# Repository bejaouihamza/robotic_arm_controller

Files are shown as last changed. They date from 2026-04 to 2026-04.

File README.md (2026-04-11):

# 🦾 6-Axis Robotic Arm Controller — RP2040

> A high-performance embedded controller for 6-axis robotic arms featuring PIO-based jitter-free PWM, per-channel current sensing, real-time torque estimation, and hardware-level collision detection — no external sensors required.







---

## 📸 PCB Renders

| 3D Render | PCB Layout | Schematic |
|:---:|:---:|:---:|
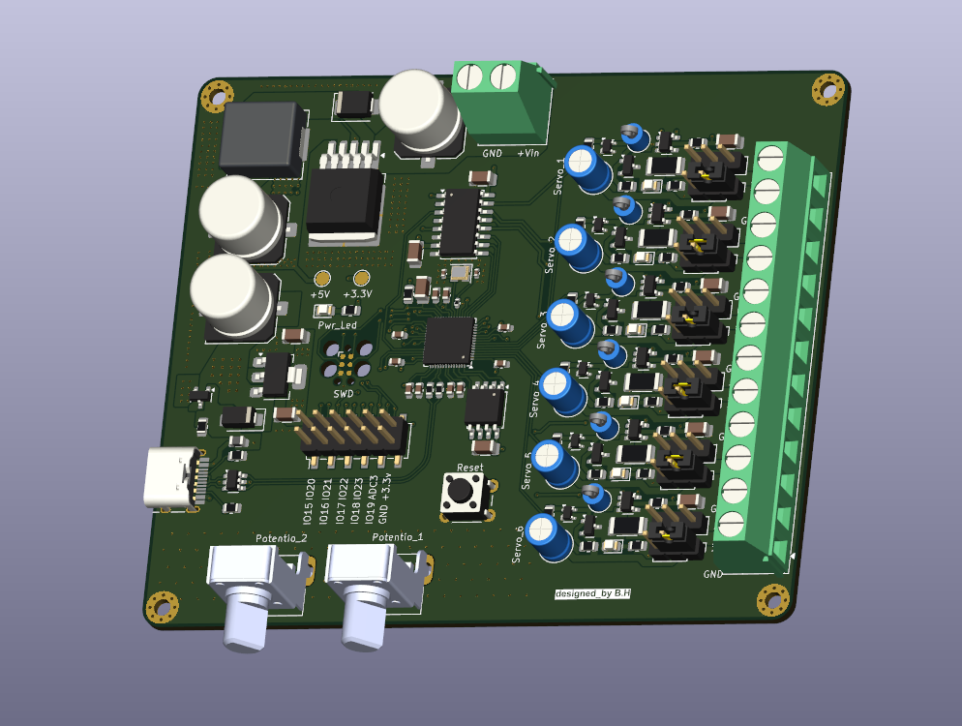
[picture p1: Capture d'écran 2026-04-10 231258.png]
3D Render
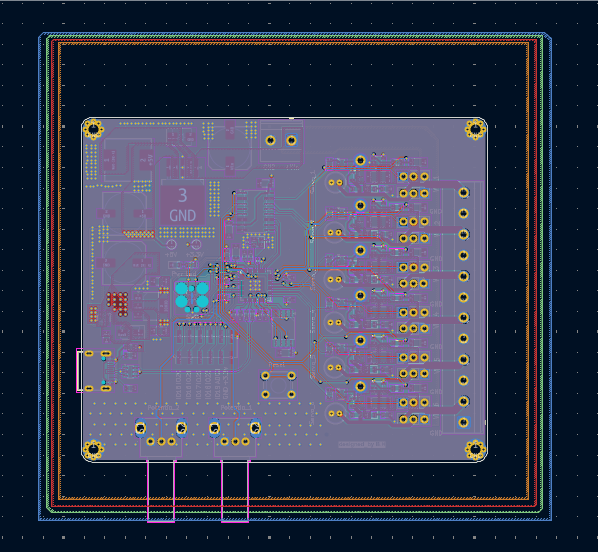
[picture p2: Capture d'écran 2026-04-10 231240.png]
PCB Layout
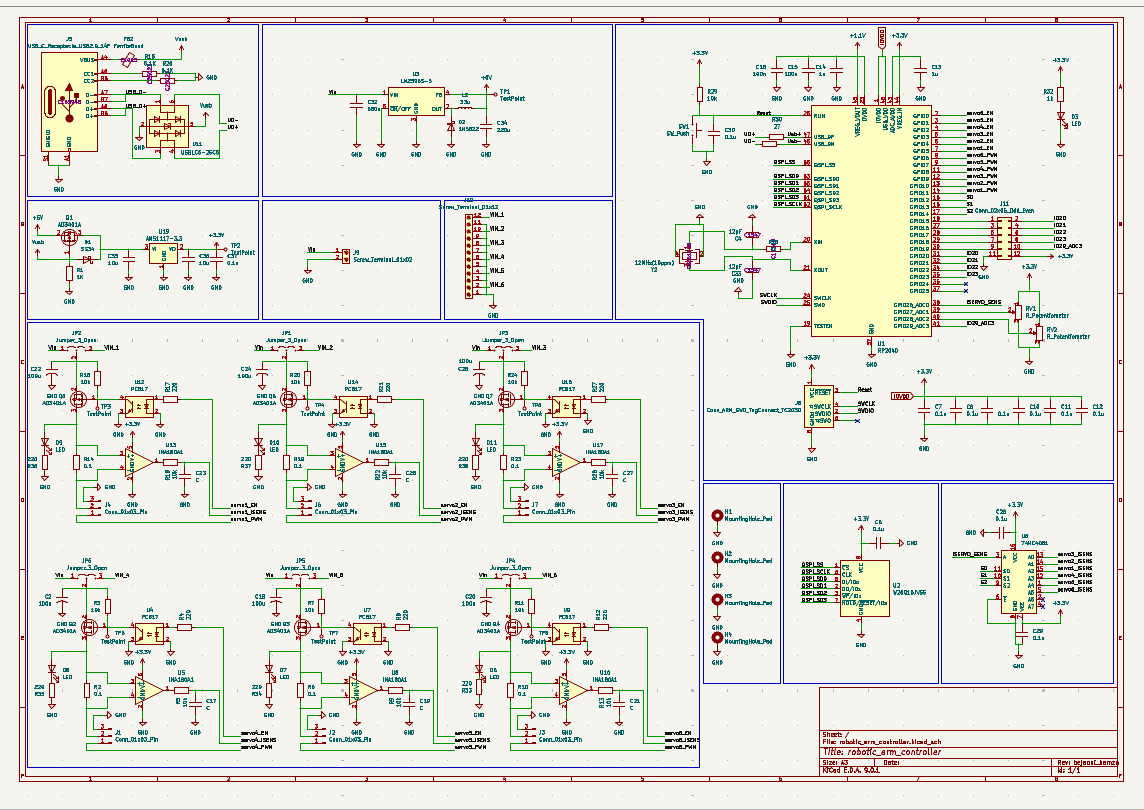
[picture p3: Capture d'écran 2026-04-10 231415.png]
Schematic
|  |  |  |

---

## ⚡ Key Specs

| Parameter | Value |
|---|---|
| MCU | Raspberry Pi RP2040 — Dual-core ARM Cortex-M0+ @ 133 MHz |
| Flash | 16MB W25Q16JV55 QSPI |
| Servo Channels | 6 independent, PIO-generated PWM |
| PWM Frequency | 50 Hz · 500–2500 µs pulse range |
| PWM Jitter | < 1 µs (PIO hardware, zero CPU involvement) |
| Current Sense | Per-channel INA180 amplifier (×20 gain, 10 mΩ shunt) |
| Peak Current | 10A total across all 6 channels |
| Input Voltage | 6V – 24V VIN + USB-C 5V |
| PCB | 4-Layer, KiCad |
| Firmware | MicroPython · C++ Pico SDK |
| License | CERN Open Hardware License v2 |

---

## 🧠 Core Concept

Traditional servo controllers simply send PWM signals. This board goes further:

```
MEASURE  →  ANALYZE  →  REACT
```

Every servo channel has a dedicated current sense amplifier. The RP2040 reads all six channels through a **74HC4051** analog multiplexer, continuously estimating torque, detecting collisions, and triggering per-channel shutdowns — all in real time.

---

## 🔩 Hardware & Components

### Processing Unit
- **RP2040** — Dual-core ARM Cortex-M0+ @ 133 MHz, 264KB SRAM, 8 PIO state machines
- **W25Q16JV55** — 16MB QSPI Flash for firmware and data logging
- **12 MHz Crystal** — Stable PLL reference for USB timing and precise PWM periods

### Power Management
- **Integrated 5V Buck Converter** — Logic supply and low-power servo rail
- **AMS1117-3.3** — Clean LDO for MCU and all analog circuitry
- **Auto power-path** — Seamless switching between USB-C (5V) and external VIN (6–24V)

### Servo Driver Block (×6 channels)
- **AO3401A P-MOSFET** — High-side switch per channel. Enables software-controlled power sequencing and instant per-joint emergency stops
- **INA180A1** — Current sense amplifier, gain ×20. Amplifies shunt voltage for ADC reading
- **10 mΩ Shunt Resistor** — In-series with each servo rail for current measurement

### Analog Signal Chain
- **74HC4051** — 8:1 CMOS analog multiplexer. Funnels all 6 current sense signals into a single ADC pin using only 3 GPIO select lines
- **JP1–JP6 Jumpers** — Per-channel voltage selection: position A = 5V buck, position B = direct VIN

### User Interface
- **RV1, RV2** — 10kΩ potentiometers mapped to Joint 1 & 2 for manual testing
- **D3** — User-programmable LED
- **Reset button** — Hardware reset
- **SWD header** — ARM Serial Wire Debug (J-Link / DAPLink / OpenOCD)

---

## 🔌 GPIO Pin Mapping

> GPIO 0–5 → Servo **Enable** (P-MOS high-side switches)  
> GPIO 6–11 → Servo **PWM** (PIO state machine outputs)

| GPIO | Net Name | Type | Connected To | Description |
|---|---|---|---|---|
| GPIO 0 | servo1_EN | GPIO OUT | AO3401A Gate Ch1 | High-side MOSFET enable — active HIGH |
| GPIO 1 | servo2_EN | GPIO OUT | AO3401A Gate Ch2 | High-side MOSFET enable — active HIGH |
| GPIO 2 | servo3_EN | GPIO OUT | AO3401A Gate Ch3 | High-side MOSFET enable — active HIGH |
| GPIO 3 | servo4_EN | GPIO OUT | AO3401A Gate Ch4 | High-side MOSFET enable — active HIGH |
| GPIO 4 | servo5_EN | GPIO OUT | AO3401A Gate Ch5 | High-side MOSFET enable — active HIGH |
| GPIO 5 | servo6_EN | GPIO OUT | AO3401A Gate Ch6 | High-side MOSFET enable — active HIGH |
| GPIO 6 | servo1_PWM | PIO OUT | Servo 1 signal wire | 50 Hz PIO PWM — sub-µs jitter |
| GPIO 7 | servo2_PWM | PIO OUT | Servo 2 signal wire | 50 Hz PIO PWM |
| GPIO 8 | servo3_PWM | PIO OUT | Servo 3 signal wire | 50 Hz PIO PWM |
| GPIO 9 | servo4_PWM | PIO OUT | Servo 4 signal wire | 50 Hz PIO PWM |
| GPIO 10 | servo5_PWM | PIO OUT | Servo 5 signal wire | 50 Hz PIO PWM |
| GPIO 11 | servo6_PWM | PIO OUT | Servo 6 signal wire | 50 Hz PIO PWM |
| GPIO 12 | S0 (MUX) | GPIO OUT | 74HC4051 Pin 11 | MUX address bit 0 |
| GPIO 13 | S1 (MUX) | GPIO OUT | 74HC4051 Pin 10 | MUX address bit 1 |
| GPIO 14 | S2 (MUX) | GPIO OUT | 74HC4051 Pin 9 | MUX address bit 2 |
| GPIO 18 | POT_1 | ADC0 IN | RV1 wiper | Manual Joint 1 input (0–3.3V = 0°–180°) |
| GPIO 19 | POT_2 | ADC1 IN | RV2 wiper | Manual Joint 2 input |
| GPIO 26 | MUX_A | GPIO OUT | 74HC4051 Pin 11 | MUX address line A |
| GPIO 27 | MUX_B | GPIO OUT | 74HC4051 Pin 10 | MUX address line B |
| GPIO 28 | MUX_C | GPIO OUT | 74HC4051 Pin 9 | MUX address line C |
| GPIO 29 | ISNS_ADC | ADC3 IN | 74HC4051 Common (Z) | Reads selected channel current sense voltage |
| USB-C | USB_DP/DM | USB 1.1 | USB-C connector | UF2 bootloader + CDC serial debug |
| SWD | SWCLK/SWDIO | DEBUG | SWD header (JB) | ARM Serial Wire Debug |

---

## 🏗️ PCB — 4-Layer Stackup

| Layer | Function | Details |
|---|---|---|
| **Layer 1 — Top** | Signal + Components | All SMD placement, fine-pitch routing (MCU, INA180, MUX) |
| **Layer 2 — GND** | Solid ground plane | Low-impedance return path, EMI shielding, heat spreading |
| **Layer 3 — Power** | Split power planes | 3.3V (MCU/sensors) · 5V (buck) · VIN (servo rails) |
| **Layer 4 — Bottom** | High-current traces | Servo power delivery, secondary signal routing |

A 4-layer design is essential here — with 6 servo channels switching simultaneously and up to 10A peak current, a 2-layer board would suffer from unacceptable EMI coupling and resistive heating.

---

## 📐 Physics — How It Works

### Motor Torque from Current

The fundamental relationship exploited by this board:

```
τ = Kₜ × I
```

A DC motor's torque is directly proportional to its armature current. `Kₜ` is the motor's torque constant (Nm/A). By measuring current through the INA180 shunt amplifiers, we measure torque — without any mechanical sensor.

### Current Sensing Chain

```
I (servo current)
  → V_shunt = I × R_shunt          (Ohm's Law across 10mΩ shunt)
  → V_out = V_shunt × 20           (INA180 ×20 amplification)
  → ADC = (V_out / 3.3V) × 65535  (RP2040 12-bit ADC)
  → I = (ADC / 65535 × 3.3) / (20 × 0.01)
```

At 2.5A (overload threshold): `V_shunt = 25mV → V_out = 500mV` — well within ADC range.

**Resolution:** ~0.25 mA per LSB → ~0.02 mNm torque resolution per LSB.

### Servo PWM Position Encoding

```
θ° = (t_pulse − 500µs) / 2000µs × 180°
```

| Pulse Width | Angle |
|---|---|
| 500 µs | 0° |
| 1500 µs | 90° (centre) |
| 2500 µs | 180° |

The RP2040's PIO state machines generate these pulses in hardware — completely independent of the CPU clock, eliminating software-induced jitter that corrupts positional accuracy.

### Why PIO Instead of Hardware PWM?

Hardware PWM slices share a clock divider. Reprogramming multiple channels simultaneously causes brief glitches. PIO state machines run from dedicated instruction memory, each executing its PWM loop independently — giving 6 perfectly phase-stable signals while freeing both CPU cores for inverse kinematics or vision tasks.

### Collision Detection — Torque Spike

When the arm hits an obstacle, the motor stalls. A stalled motor draws its locked-rotor current — far above normal running current:

```
Normal:  I ≈ 0.3–0.8 A  →  τ ≈ 0.025–0.068 Nm
Stall:   I → 2–4 A      →  τ → 0.17–0.34 Nm  ← triggers shutdown
```

The ADC scans all 6 channels continuously. A torque spike is detected within one scan cycle (~1 ms). The P-MOSFET cuts power within a single GPIO toggle (~10 ns).

---

## 🛡️ Safety System

| Feature | Description |
|---|---|
| **Torque Estimation** | τ = Kₜ × I, live on all 6 joints, ~0.02 mNm resolution |
| **Collision Detection** | Configurable torque threshold (default 0.20 Nm) triggers per-joint shutdown |
| **Overcurrent Protection** | Sustained current > 2.5A sets latching fault, cuts P-MOSFET |
| **Emergency Stop** | All 6 channels cut simultaneously via single function call |
| **Smooth Motion** | Interpolated moves with per-step collision check |
| **Power Sequencing** | Staggered joint enable (100ms delay) prevents inrush brownout |
| **Fault Latch** | Fault persists until software reset — prevents repeated thermal stress |

---

## 💻 Firmware

```python
# robotic_arm_controller.py
# GPIO 0-5  → Servo ENABLE (P-MOS high-side switches)
# GPIO 6-11 → Servo PWM    (PIO state machines)
import rp2, machine, time

SERVO_EN_PINS  = [0, 1, 2, 3, 4, 5]
SERVO_PWM_PINS = [6, 7, 8, 9, 10, 11]
MUX_SEL_PINS   = [12, 13, 14]
ADC_ISNS_PIN   = 29
POT1_PIN, POT2_PIN = 18, 19

SERVO_MIN_US = 500
SERVO_MAX_US = 2500
ISNS_GAIN    = 20
SHUNT_R      = 0.010
OVERLOAD_A   = 2.5
KT_NM_PER_A  = 0.085
COLLISION_NM = 0.20

@rp2.asm_pio(sideset_init=rp2.PIO.OUT_LOW)
def servo_pwm_pio():
    pull(block)          .side(0)
    mov(x, osr)
    label("high_loop")
    jmp(x_dec, "high_loop")  .side(1)
    pull(block)          .side(1)
    mov(x, osr)
    label("low_loop")
    jmp(x_dec, "low_loop")   .side(0)

class ServoChannel:
    def __init__(self, en_pin, pwm_pin, sm_id):
        self.en = machine.Pin(en_pin, machine.Pin.OUT, value=0)
        self.sm = rp2.StateMachine(sm_id, servo_pwm_pio,
                    freq=2_000_000, sideset_base=machine.Pin(pwm_pin))
        self.sm.active(1)
        self.angle = 90
        self.set_angle(90)

    def power_on(self):  self.en.value(1)
    def power_off(self): self.en.value(0)

    def set_angle(self, deg):
        deg = max(0.0, min(180.0, float(deg)))
        us  = SERVO_MIN_US + (deg / 180.0) * (SERVO_MAX_US - SERVO_MIN_US)
        self.sm.put(int(us * 2))
        self.sm.put(int((20000 - us) * 2))
        self.angle = deg

class CurrentSensor:
    def __init__(self):
        self.mux = [machine.Pin(p, machine.Pin.OUT) for p in MUX_SEL_PINS]
        self.adc = machine.ADC(ADC_ISNS_PIN)

    def read_channel(self, ch):
        for i, pin in enumerate(self.mux):
            pin.value((ch >> i) & 1)
        time.sleep_us(5)
        v = (self.adc.read_u16() / 65535) * 3.3
        return round(v / (ISNS_GAIN * SHUNT_R), 4)

    def read_all(self):
        return [self.read_channel(i) for i in range(6)]

class RoboticArm:
    def __init__(self):
        self.joints = [ServoChannel(SERVO_EN_PINS[i], SERVO_PWM_PINS[i], i) for i in range(6)]
        self.isns   = CurrentSensor()
        self.pot1   = machine.ADC(POT1_PIN)
        self.pot2   = machine.ADC(POT2_PIN)
        self.fault  = [False] * 6

    def power_up_sequence(self, delay_ms=100):
        for j in self.joints:
            j.power_on()
            time.sleep_ms(delay_ms)

    def emergency_stop(self):
        for j in self.joints: j.power_off()
        print("[E-STOP] All channels cut")

    def move_to(self, angles):
        for i, (j, deg) in enumerate(zip(self.joints, angles)):
            if not self.fault[i]: j.set_angle(deg)

    def torque_estimate(self):
        return [round(a * KT_NM_PER_A, 4) for a in self.isns.read_all()]

    def detect_collision(self, threshold_nm=COLLISION_NM):
        hits = []
        for i, t in enumerate(self.torque_estimate()):
            if t > threshold_nm and not self.fault[i]:
                self.joints[i].power_off()
                self.fault[i] = True
                hits.append(i)
                print(f"[COLLISION] Joint {i+1} @ {t:.4f} Nm")
        return hits

    def check_overload(self):
        for i, a in enumerate(self.isns.read_all()):
            if a > OVERLOAD_A and not self.fault[i]:
                self.joints[i].power_off()
                self.fault[i] = True
                print(f"[FAULT] Joint {i+1} overcurrent: {a:.3f} A")

    def smooth_move(self, targets, steps=50, delay_ms=10):
        start = [j.angle for j in self.joints]
        for s in range(1, steps + 1):
            t = s / steps
            self.move_to([start[i] + t * (targets[i] - start[i]) for i in range(6)])
            self.check_overload()
            if self.detect_collision(): return False
            time.sleep_ms(delay_ms)
        return True

    def read_manual(self):
        return (round((self.pot1.read_u16() / 65535) * 180, 1),
                round((self.pot2.read_u16() / 65535) * 180, 1))

    def status(self):
        c = self.isns.read_all()
        t = self.torque_estimate()
        print(f"{'Joint':<8}{'Angle':>8}{'Current':>10}{'Torque':>10}{'State':>8}")
        print("-" * 46)
        for i in range(6):
            print(f"J{i+1:<7}{self.joints[i].angle:>7.1f}°{c[i]:>9.3f}A{t[i]:>9.4f}Nm{'FAULT' if self.fault[i] else 'OK':>8}")

# ── Main ──────────────────────────────────────────────────
arm = RoboticArm()
arm.power_up_sequence(delay_ms=120)
arm.smooth_move([90, 90, 90, 90, 90, 90])

while True:
    j1, j2 = arm.read_manual()
    arm.move_to([j1, j2, 90, 90, 90, 90])
    arm.check_overload()
    arm.detect_collision()
    arm.status()
    time.sleep_ms(20)
```

---

## 🚀 Getting Started

**1. Power the board**
Connect VIN (6–24V) to the screw terminal. Set jumpers JP1–JP6:
- Position **A** → 5V internal buck (standard hobby servos)
- Position **B** → Direct VIN (high-torque servos above 7.4V)

**2. Flash firmware**
Hold `BOOT` on the back, press `RESET`. A drive named `RPI-RP2` appears. Drag your `.uf2` file onto it. Board reboots and runs automatically.

**3. Test with potentiometers**
RV1 and RV2 control Joint 1 and Joint 2 by default. Rotate to verify servo response before connecting the full arm.

**4. Monitor over serial**
Open any terminal at **115200 baud** on the USB-C port. `arm.status()` prints a live table of angle, current, torque, and fault state for all 6 joints.

**5. Tune collision thresholds**
Run the arm freely and log `status()` output. Set `COLLISION_NM` to ~1.5–2× the maximum torque observed during normal free movement.

**6. Extend with C++ for performance**
Run motion control on Core 0 and current sensing on Core 1 for fully parallel deterministic operation. Core 1 can achieve scan rates exceeding 10 kHz — enabling sub-millisecond collision response.

---

## ✅ Capabilities

- 6 independent PIO-generated PWM channels — sub-microsecond jitter
- Real-time torque estimation on every joint — no mechanical sensors
- Per-channel collision detection with configurable threshold
- Individual high-side MOSFET shutdown per channel
- Emergency stop — all 6 channels cut within a single GPIO toggle
- Smooth interpolated motion with mid-move collision check
- Staggered power-up to prevent inrush brownout
- Manual joint control via onboard potentiometers
- USB-C UF2 flashing — no external programmer required
- SWD debug header — J-Link / DAPLink / OpenOCD compatible
- Dual-core execution: motion on Core 0, sensing on Core 1
- MicroPython and C++ Pico SDK fully supported
- Per-servo independent voltage selection via JP1–JP6
- Live status table: angle, current, torque, fault per joint
- Latching fault system with software reset
- CERN Open Hardware License — free to modify and manufacture

---

## 📄 License

Released under the **CERN Open Hardware Licence Version 2 — Strongly Reciprocal (CERN-OHL-S v2)**.  
Free to study, modify, manufacture, and distribute — derivatives must remain open source.

---

<div align="center">Designed by <strong>B.H</strong></div>

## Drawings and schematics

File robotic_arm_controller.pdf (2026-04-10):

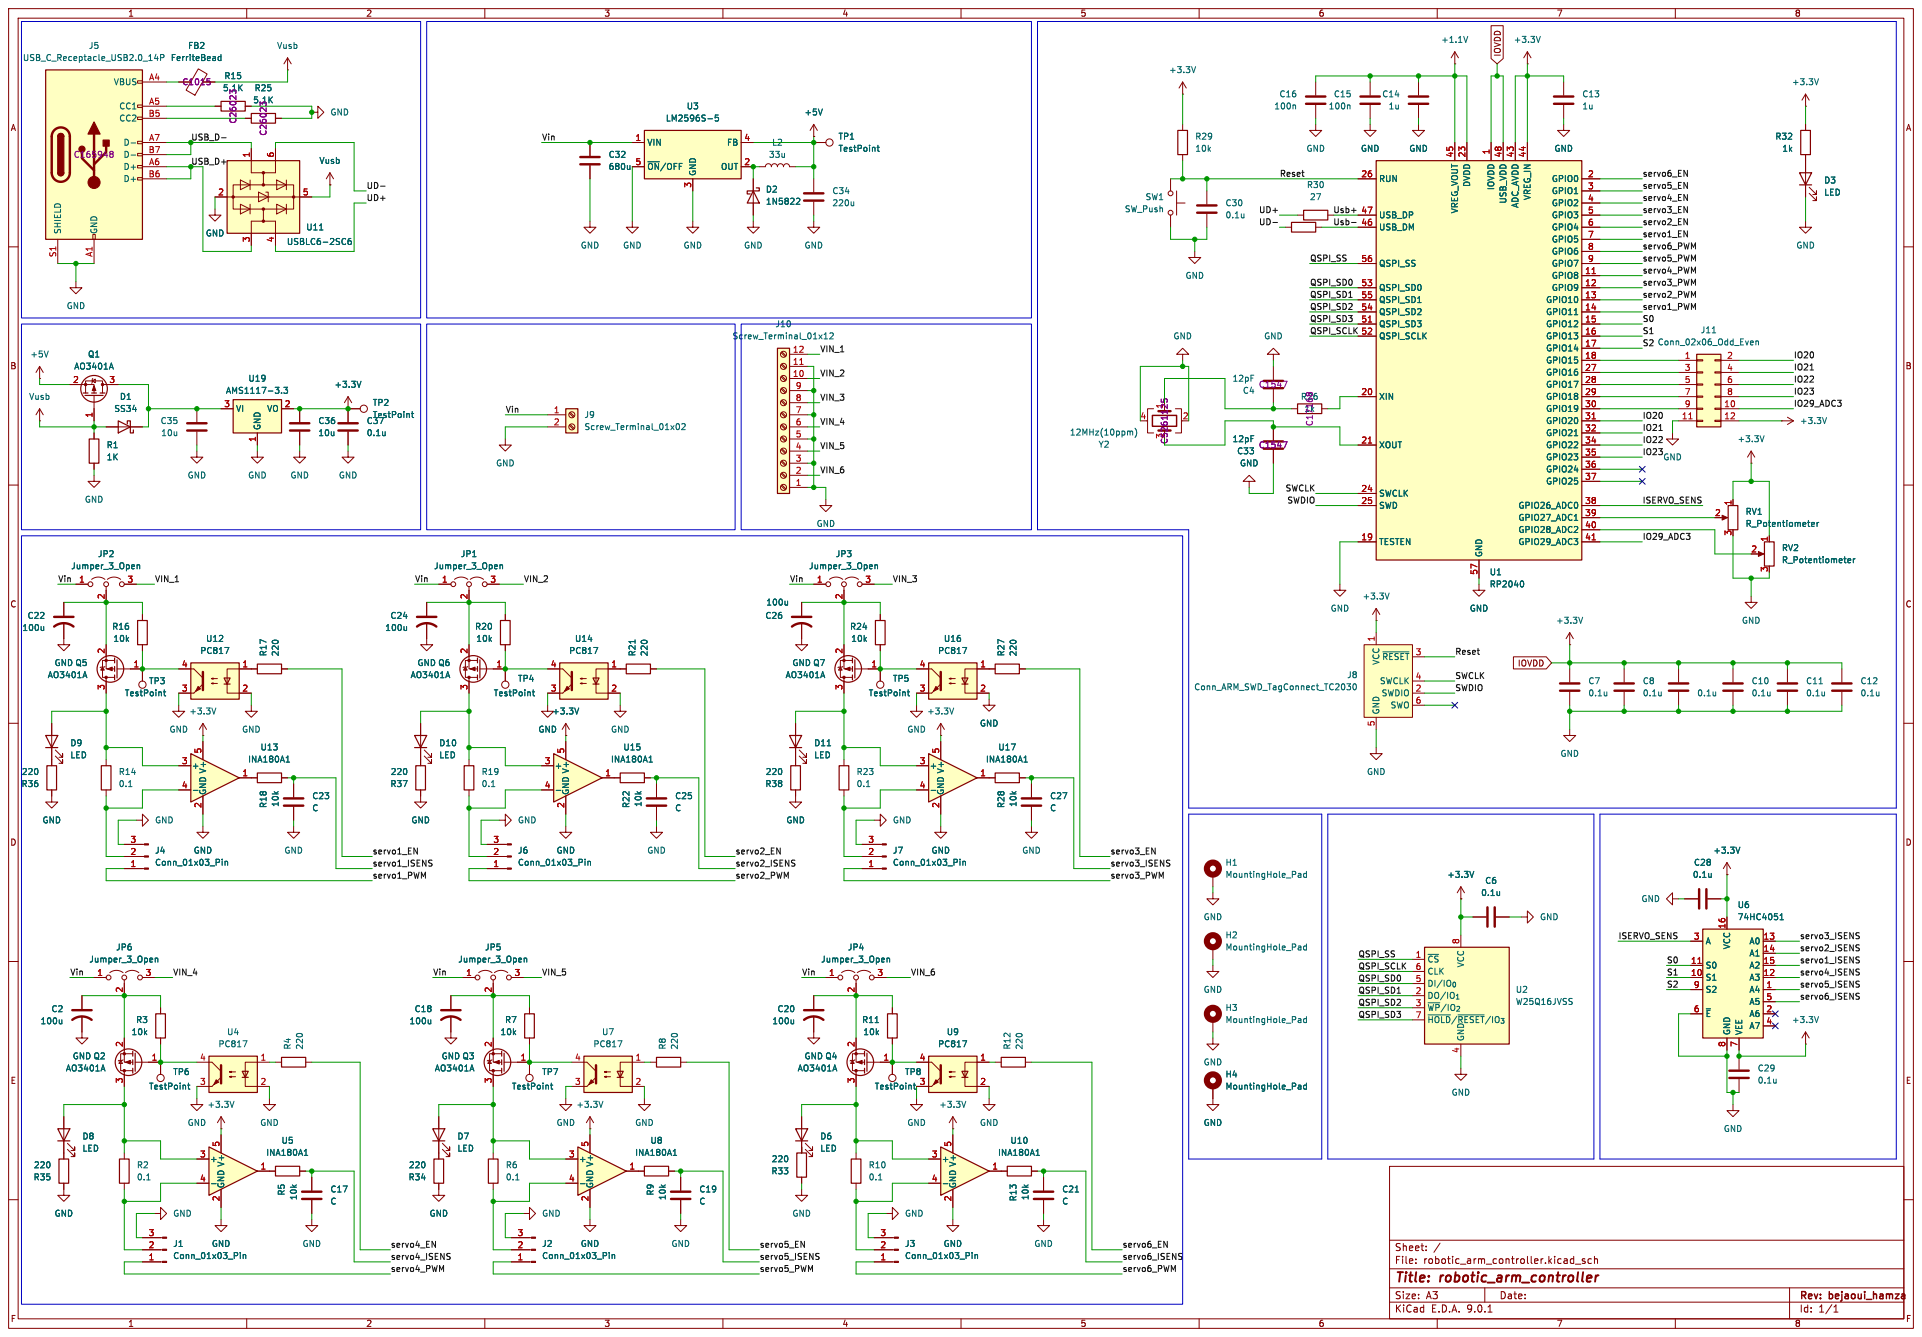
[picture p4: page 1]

5 ~{RESET}3 SWCLK 4 SWDIO 2 SWO 6

Id: 1/1 Title: robotic_arm_controller File: robotic_arm_controller.kicad_sch Sheet: / GND

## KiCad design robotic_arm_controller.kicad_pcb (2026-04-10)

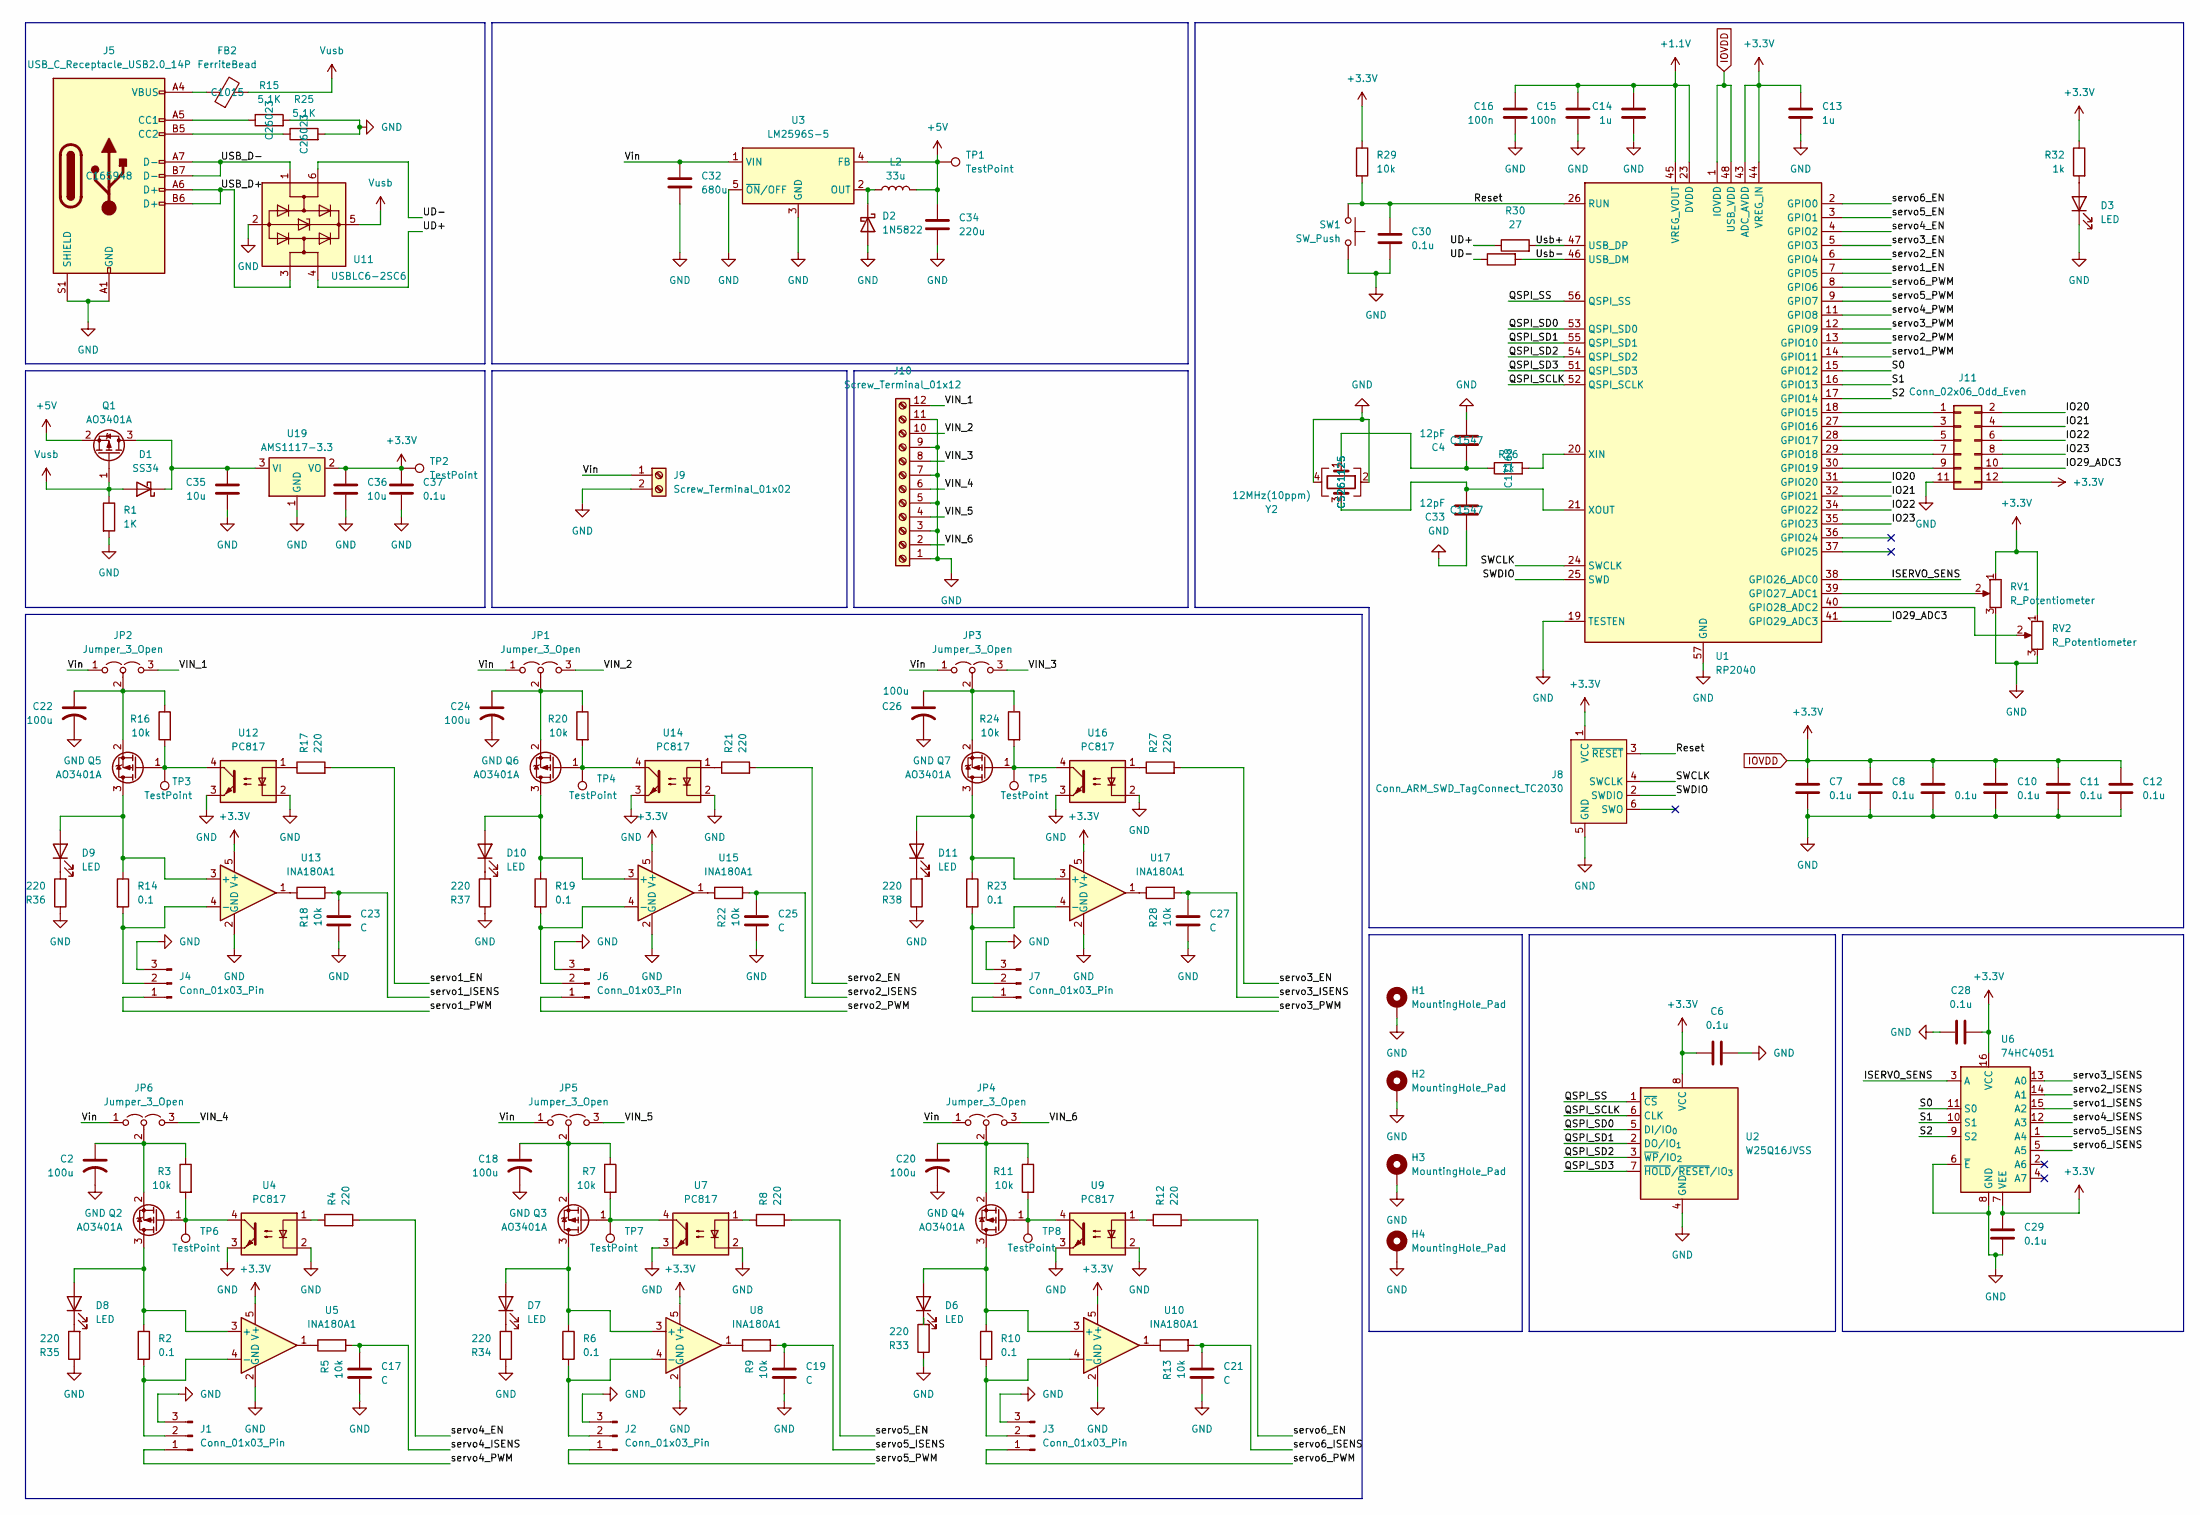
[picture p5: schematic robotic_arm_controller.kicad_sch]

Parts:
C2, C18, C20, C22, C24, C26: 100u; C_Radial_D5.0mm_H7.0mm_P2.00mm
C4, C33: 12pF; C_0402_1005Metric; MNF PART NUMBER C1547; LCSC Part # C1547
C6, C28, C29, C30, C37: 0.1u; C_1206_3216Metric
C7, C8, C9, C10, C11, C12: 0.1u; C_0603_1608Metric
C13, C14: 1u; C_0603_1608Metric
C15, C16: 100n; C_0603_1608Metric
C17, C19, C21, C23, C25, C27: C; C_1206_3216Metric
C32: 680u; C_Elec_10x10.2
C34: 220u; C_Elec_10x10.2
C35: 10u; C_Elec_10x10.2
C36: 10u; C_1206_3216Metric
D1: SS34; D_SMA
D2: 1N5822; D_SMB
D3, D6, D7, D8, D9, D10, D11: LED; LED_0805_2012Metric
FB2: FerriteBead; L_0805_2012Metric; LCSC Part # C1015
H1, H2, H3, H4: MountingHole_Pad; MountingHole_2.5mm_Pad_Via
J1, J2, J3, J4, J6, J7: Conn_01x03_Pin; PinHeader_1x03_P2.54mm_Vertical
J5: USB_C_Receptacle_USB2.0_14P; USB_C_Receptacle_HRO_TYPE-C-31-M-12; LCSC Part # C165948
J8: Conn_ARM_SWD_TagConnect_TC2030; Tag-Connect_TC2030-IDC-FP_2x03_P1.27mm_Vertical
J9: Screw_Terminal_01x02; TerminalBlock_Phoenix_MKDS-1,5-2-5.08_1x02_P5.08mm_Horizont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
J10: Screw_Terminal_01x12; TerminalBlock_Phoenix_MKDS-1,5-12-5.08_1x12_P5.08mm_Horizon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
J11: Conn_02x06_Odd_Even; PinHeader_2x06_P2.54mm_Vertical_SMD
JP1, JP2, JP3, JP4, JP5, JP6: Jumper_3_Open; PinHeader_1x03_P2.54mm_Vertical
L2: 33u; L_Bourns_SRP1050WA
Q1, Q2, Q3, Q4, Q5, Q6, Q7: AO3401A; SOT-23
R1: 1K; R_0805_2012Metric
R2, R6, R10, R14, R19, R23: 0.1; R_2010_5025Metric
R3, R5, R7, R9, R11, R13, R16, R18, R20, R22, R24, R28, R29: 10k; R_0805_2012Metric
R4, R8, R12, R17, R21, R27, R33, R34, R35, R36, R37, R38: 220; R_0805_2012Metric
R15, R25: 5.1K; R_0805_2012Metric; LCSC Part # C26023
R26: 1k; R_0402_1005Metric; MNF PART NUMBER C17168; LCSC Part # C17168
R30, R31: 27; R_0603_1608Metric
R32: 1k; R_0805_2012Metric
RV1, RV2: R_Potentiometer; TRIM_PT01-B115D-B103
SW1: SW_Push; SW_PUSH_6mm_H5mm
TP1, TP2: TestPoint; TestPoint_Pad_D2.0mm
TP3, TP4, TP5, TP6, TP7, TP8: TestPoint; TestPoint_Keystone_5005-5009_Compact
U1: RP2040; QFN-56-1EP_7x7mm_P0.4mm_EP3.2x3.2mm
U2: W25Q16JVSS; SOIC-8_5.3x5.3mm_P1.27mm
U3: LM2596S-5; TO-263-5_TabPin3
U4, U7, U9, U12, U14, U16: PC817; Analog_KS-4
U5, U8, U10, U13, U15, U17: INA180A1; SOT-23-5
U6: 74HC4051; SOIC-16W_5.3x10.2mm_P1.27mm
U11: USBLC6-2SC6; SOT-23-6; Manufacturer_Part_Number USBLC6-2SC6; Mouser Part Number 511-USBLC6-2SC6
U19: AMS1117-3.3; SOT-223-3_TabPin2
Y2: 12MHz(10ppm); Crystal_SMD_2520-4Pin_2.5x2.0mm; MNF PART NUMBER C5261125; LCSC Part # C5261125

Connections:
+1.1V: C14.2, C15.2, C16.2, U1.23 (DVDD), U1.45 (VREG_VOUT), U1.50 (DVDD)
+5V: C34.1, L2.2, Q1.2 (S), TP1.1, U3.4 (FB)
/IO20: J11.2, U1.31 (GPIO20)
/IO21: J11.4, U1.32 (GPIO21)
/IO22: J11.6, U1.34 (GPIO22)
/IO23: J11.8, U1.35 (GPIO23)
/IO29_ADC3: J11.10, U1.41 (GPIO29_ADC3)
/ISERVO_SENS: U1.38 (GPIO26_ADC0), U6.3 (A)
/QSPI_SCLK: U1.52 (QSPI_SCLK), U2.6 (CLK)
/QSPI_SD0: U1.53 (QSPI_SD0), U2.5 (DI/IO_{0})
/QSPI_SD1: U1.55 (QSPI_SD1), U2.2 (DO/IO_{1})
/QSPI_SD2: U1.54 (QSPI_SD2), U2.3 (~WP/IO_{2})
/QSPI_SD3: U1.51 (QSPI_SD3), U2.7 (~HOLD/~RESET/IO_{3})
/QSPI_SS: U1.56 (QSPI_SS), U2.1 (~CS)
/Reset: C30.2, J8.3 (~RESET), R29.2, SW1.2, U1.26 (RUN)
/S0: U1.15 (GPIO12), U6.11 (S0)
/S1: U1.16 (GPIO13), U6.10 (S1)
/S2: U1.17 (GPIO14), U6.9 (S2)
/SWCLK: J8.4 (SWCLK), U1.24 (SWCLK)
/SWDIO: J8.2 (SWDIO), U1.25 (SWD)
/UD+: R30.1, U11.4 (I/O2)
/UD-: R31.1, U11.6 (I/O1)
/USB_D+: J5.A6 (D+), J5.B6 (D+), U11.3 (I/O2)
/USB_D-: J5.A7 (D-), J5.B7 (D-), U11.1 (I/O1)
/Usb+: R30.2, U1.47 (USB_DP)
/Usb-: R31.2, U1.46 (USB_DM)
/VIN_1: J10.12, JP2.3 (B)
/VIN_2: J10.10, JP1.3 (B)
/VIN_3: J10.8, JP3.3 (B)
/VIN_4: J10.6, JP6.3 (B)
/VIN_5: J10.4, JP5.3 (B)
/VIN_6: J10.2, JP4.3 (B)
/Vin: C32.1, J9.1, JP1.1 (A), JP2.1 (A), JP3.1 (A), JP4.1 (A), JP5.1 (A), JP6.1 (A), U3.1 (VIN)
/servo1_EN: R17.2, U1.7 (GPIO5)
/servo1_ISENS: C23.1, R18.2, U6.15 (A2)
/servo1_PWM: J4.1, U1.14 (GPIO11)
/servo2_EN: R21.2, U1.6 (GPIO4)
/servo2_ISENS: C25.1, R22.2, U6.14 (A1)
/servo2_PWM: J6.1, U1.13 (GPIO10)
/servo3_EN: R27.2, U1.5 (GPIO3)
/servo3_ISENS: C27.1, R28.2, U6.13 (A0)
/servo3_PWM: J7.1, U1.12 (GPIO9)
/servo4_EN: R4.2, U1.4 (GPIO2)
/servo4_ISENS: C17.1, R5.2, U6.12 (A3)
/servo4_PWM: J1.1, U1.11 (GPIO8)
/servo5_EN: R8.2, U1.3 (GPIO1)
/servo5_ISENS: C19.1, R9.2, U6.1 (A4)
/servo5_PWM: J2.1, U1.9 (GPIO7)
/servo6_EN: R12.2, U1.2 (GPIO0)
/servo6_ISENS: C21.1, R13.2, U6.5 (A5)
/servo6_PWM: J3.1, U1.8 (GPIO6)
GND: C2.2, C4.2, C6.2, C7.1, C8.1, C9.1, C10.1, C11.1, C12.1, C13.1, C14.1, C15.1, C16.1, C17.2, C18.2, C19.2, C20.2, C21.2, C22.2, C23.2, C24.2, C25.2, C26.2, C27.2, C28.1, C29.1, C30.1, C32.2, C33.1, C34.2, C35.2, C36.2, C37.2, D2.2 (A), D3.1 (K), H1.1, H2.1, H3.1, H4.1, J1.3, J2.3, J3.3, J4.3, J5.A1 (GND), J5.A12 (GND), J5.B1 (GND), J5.B12 (GND), J5.S1 (SHIELD), J6.3, J7.3, J8.5 (GND), J9.2, J10.1, J10.3, J10.5, J10.7, J10.9, J10.11, J11.11, R1.2, R15.2, R25.2, R33.1, R34.1, R35.1, R36.1, R37.1, R38.1, RV1.3, RV2.3, SW1.1, U1.19 (TESTEN), U1.57 (GND), U2.4 (GND), U3.3 (GND), U3.5 (~ON/OFF), U4.2, U4.3, U5.2 (GND), U6.6 (~E), U6.8 (GND), U7.2, U7.3, U8.2 (GND), U9.2, U9.3, U10.2 (GND), U11.2 (GND), U12.2, U12.3, U13.2 (GND), U14.2, U14.3, U15.2 (GND), U16.2, U16.3, U17.2 (GND), U19.1 (GND), Y2.2, Y2.4
IOVDD: C6.1, C7.2, C8.2, C9.2, C10.2, C11.2, C12.2, C13.2, C28.2, C29.2, C36.1, C37.1, J8.1 (VCC), J11.12, R29.1, R32.1, RV1.1, RV2.1, TP2.1, U1.1 (IOVDD), U1.10 (IOVDD), U1.22 (IOVDD), U1.33 (IOVDD), U1.42 (IOVDD), U1.43 (ADC_AVDD), U1.44 (VREG_IN), U1.48 (USB_VDD), U1.49 (IOVDD), U2.8 (VCC), U5.5 (V+), U6.7 (VEE), U6.16 (VCC), U8.5 (V+), U10.5 (V+), U13.5 (V+), U15.5 (V+), U17.5 (V+), U19.2 (VO)
unnamed: C4.1, R26.1, Y2.1
unnamed: C35.1, D1.1 (K), Q1.3 (D), U19.3 (VI)
unnamed: D2.1 (K), L2.1, U3.2 (OUT)
unnamed: D3.2 (A), R32.2
unnamed: D6.2 (A), Q4.3 (D), R10.1, U10.3 (+)
unnamed: D6.1 (K), R33.2
unnamed: D7.2 (A), Q3.3 (D), R6.1, U8.3 (+)
unnamed: D7.1 (K), R34.2
unnamed: D8.2 (A), Q2.3 (D), R2.1, U5.3 (+)
unnamed: D8.1 (K), R35.2
unnamed: D9.2 (A), Q5.3 (D), R14.1, U13.3 (+)
unnamed: D9.1 (K), R36.2
unnamed: D10.2 (A), Q6.3 (D), R19.1, U15.3 (+)
unnamed: D10.1 (K), R37.2
unnamed: D11.2 (A), Q7.3 (D), R23.1, U17.3 (+)
unnamed: D11.1 (K), R38.2
unnamed: FB2.1, J5.A4 (VBUS), J5.A9 (VBUS), J5.B4 (VBUS), J5.B9 (VBUS)
unnamed: J1.2, R2.2, U5.4 (-)
unnamed: J2.2, R6.2, U8.4 (-)
unnamed: J3.2, R10.2, U10.4 (-)
unnamed: J4.2, R14.2, U13.4 (-)
unnamed: J5.A5 (CC1), R15.1
unnamed: J5.B5 (CC2), R25.1
unnamed: J6.2, R19.2, U15.4 (-)
unnamed: J7.2, R23.2, U17.4 (-)
unnamed: J11.1, U1.18 (GPIO15)
unnamed: J11.3, U1.27 (GPIO16)
unnamed: J11.5, U1.28 (GPIO17)
unnamed: J11.7, U1.29 (GPIO18)
unnamed: J11.9, U1.30 (GPIO19)
unnamed: C24.1, JP1.2 (C), Q6.2 (S), R20.1
unnamed: C22.1, JP2.2 (C), Q5.2 (S), R16.1
unnamed: C26.1, JP3.2 (C), Q7.2 (S), R24.1
unnamed: C20.1, JP4.2 (C), Q4.2 (S), R11.1
unnamed: C18.1, JP5.2 (C), Q3.2 (S), R7.1
unnamed: C2.1, JP6.2 (C), Q2.2 (S), R3.1
unnamed: Q2.1 (G), R3.2, TP6.1, U4.4
unnamed: Q3.1 (G), R7.2, TP7.1, U7.4
unnamed: Q4.1 (G), R11.2, TP8.1, U9.4
unnamed: Q5.1 (G), R16.2, TP3.1, U12.4
unnamed: Q6.1 (G), R20.2, TP4.1, U14.4
unnamed: Q7.1 (G), R24.2, TP5.1, U16.4
unnamed: R4.1, U4.1
unnamed: R5.1, U5.1
unnamed: R8.1, U7.1
unnamed: R9.1, U8.1
unnamed: R12.1, U9.1
unnamed: R13.1, U10.1
unnamed: R17.1, U12.1
unnamed: R18.1, U13.1
unnamed: R21.1, U14.1
unnamed: R22.1, U15.1
unnamed: R27.1, U16.1
unnamed: R28.1, U17.1
unnamed: RV1.2, U1.39 (GPIO27_ADC1)
unnamed: RV2.2, U1.40 (GPIO28_ADC2)
unnamed: R26.2, U1.20 (XIN)
unnamed: C33.2, U1.21 (XOUT), Y2.3
Vusb: D1.2 (A), FB2.2, Q1.1 (G), R1.1, U11.5 (VBUS)

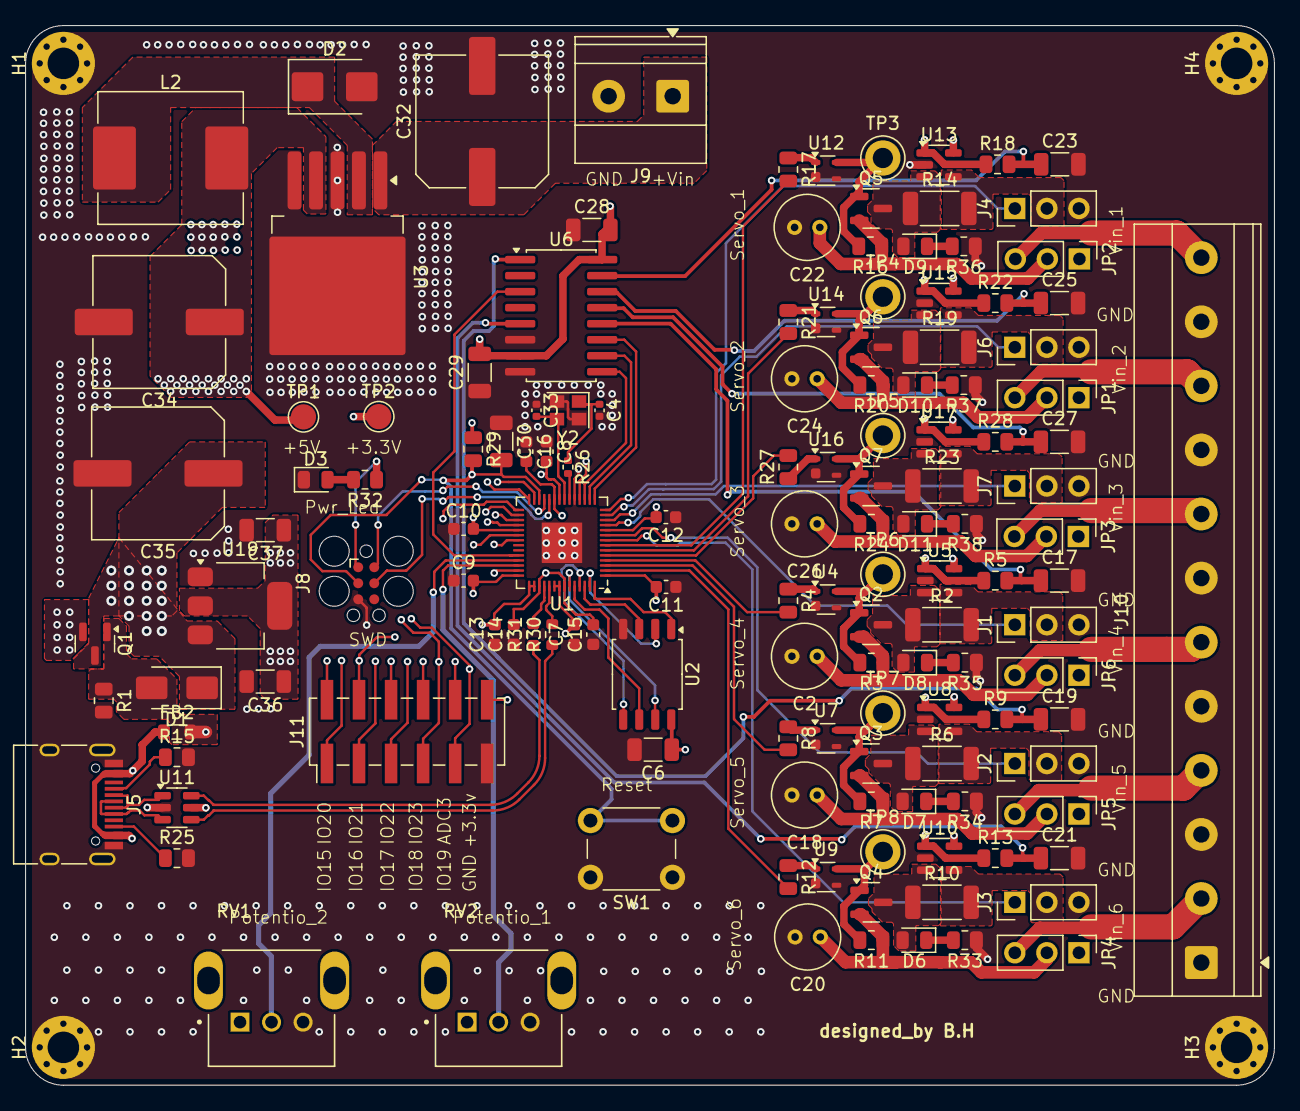
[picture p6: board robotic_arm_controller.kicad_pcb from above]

Board: 4 copper layers, 99.0 x 84.0 mm, 140 parts (0 on the bottom side), 112 nets.

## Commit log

2026-04-10 Create servo6_control
2026-04-11 Create README.md for robotic arm controller
    Add detailed README for 6-axis robotic arm controller including specifications, features, and setup instructions.

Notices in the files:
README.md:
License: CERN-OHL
